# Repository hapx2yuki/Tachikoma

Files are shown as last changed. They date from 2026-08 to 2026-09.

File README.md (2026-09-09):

# タチコマ歩行ロボット化プロジェクト

`TACHIKOMA.3mf` (可動フィギュアの 3D 印刷キット) を、**12 サーボで歩行し、
2 本の可動腕 (キット準拠の固定爪を持つ) を持ち、スマホから操作できる
ロボット**へ改造するプロジェクト。

**2026-09-05 第2次監査結果:** 実サーボの占有、固定部品内部、挿入経路、材料別接触、実制御とSTL変換まで検査し、再現した不具合を修正。
全STL/URDFを再生成したが、頭内収納・頭固定・首/Cabin・脚装飾・足裏支持に未解決事項があり、そのまま組立歩行できる設計とは判定していない。
本文の旧「全検証PASS」は当時の検査範囲の記録であり、組立・実機歩行の合格を示さない。
公開候補の最新記録は[2026-09-09再開監査](docs/audits/20260909-resume/README.md)です（WIP）。
これは実印刷・実組立・通電・歩行の完了を示しません。設計の根拠・残課題は[第2次監査](docs/audits/20260905-round2/README.md)と
[監査Issue #80](https://github.com/hapx2yuki/Tachikoma/issues/80)を参照。

**追加で揃えるもの:** [印刷優先構成の現在地](docs/print-first.md) / [追加購入の全一覧](docs/additional-purchases.md) / [追加印刷・再使用の全一覧](docs/additional-printing.md)。必要総数と手持ちの確認済み数量を区別し、設計未確定の部品を発注・一括印刷する指示にはしていない。[全Issuesの更新内容と着手条件](docs/issues-audit-20260905.md)も参照。

> **Disclaimer / 免責**: 本プロジェクトは『攻殻機動隊』に登場するタチコマを
> モチーフにした**非公式・非営利の個人ファン制作**であり、士郎正宗氏・
> 講談社・Production I.G ほか原作の権利者とは一切関係ありません。
> 商用利用・販売は意図していません。
>
> **License**: コード (`tools/` `hardware/src/` `firmware/`) は
> [MIT](LICENSE)。3D モデルデータ・ドキュメント・メディアは
> [CC BY-NC-SA 4.0](LICENSE-MODELS.md) (非営利・表示・継承)。
> ビルドして遊ぶのは自由ですが、モデルデータの商用利用はできません。

- 意匠シェル: 元モデルを 150% で印刷 (全長 ~38cm)、印刷機は Bambu Lab X2D
- 脚: 3DOF×4 (股ヨー/股ピッチ/膝)。**全軸 20kg 級標準サーボ (DS3218 系,
  デュアルベアリング出力軸)**。骨格は新規設計、シェルを被せて外観維持
- 腕: 3DOF×2 (肩ヨー/肩ピッチ/肘 = MG90S)。手は**キット準拠の固定爪**
  (2026-07-29 可動グリッパから変更: 「爪は可動不要」というユーザー方針に
  基づき、可動グリッパ機構 [palm_base/grip_slider/grip_finger + サブ
  マイクロ×2] を廃止し、元キットの Claw_Grey [爪ハブ] + Finger_Black×3
  [指, 差込] + FingerTip_Grey×3 [指先チップ, 接着] を無加工のまま前腕終端
  の claw_mount へ接着する構成に単純化)。**実機準拠でシャーシ前縁下面から
  吊り下げ**、寸法はキット実測比率 (肘→爪直結の短い腕。3MF フォレンジクス
  実測で前腕を 24→16mm に再短縮)。**意匠は元キットパーツ**: 上腕 = Arm
  ポッドのクラムシェル被せ、肘 = Elbow 球の半殻、爪ハブ/指/指先チップは
  無加工のキット STL そのもの。プリセット TUCK/READY/REACH/WAVE + 各軸
  個別操作 (肩ヨー/肩ピッチ/肘の 3 軸のみ、グリップ軸は無し)
- 制御: ESP32 + PCA9685 ×2 (0x40 脚+頭 / 0x41 腕+目)。WiFi AP (操作UI
  フォールバック) + STA (iPhone インターネット共有へ join) + スマホブラウザ
- 歩容: 回転順クロール (RL→FL→FR→RR) + 重心シフト 前脚 34 / 後脚 40mm + 中立足先を実重心側
  (y=-39mm, Cabin が主因) へ 30mm オフセット → 実重心基準の静的安定 +10.9mm (2026-09-04)
- **目**: **元キットの目パーツ (Head_Eye_White) の形状をそのまま可動化**。
  左右 2 目は白い扁平ドームの黒ドット群 (モールド穴を黒仕上げ) がキャップ軸
  から ~45° 偏心しているため、サブマイクロ ×2 の自軸回転だけで視線が泳ぐ
  **キョロキョロ機構** (掃引径 ~28mm。ランダムサッカード/正面固定/スキャン
  の 3 モード + 歩行方向への視線バイアス)。**中央目は固定カメラ目**
  (下記「カメラ」参照, 2026-07-28 設計変更)。Head_Top の目ソケット
  (φ42.3 座グリ, STL 実測) の底へ φ30 貫通ボアを開け (Head_Top_Eyecut.stl
  生成済み)、シェル内側から嵌める
- ギミック: WS2812 LED (目バックライト/赤ランプ)、DFPlayer サウンド。頭部は
  完全固定 (可動部なし, `docs/assembly.md` §3)。未実装の頭部ヨーに対応する
  CH_HEAD/ch12は、現在のfirmwareでは常時出力停止。
- **音声会話**: 砲身 (Mouth_Cannon) 内蔵のマイク (INMP441) + スピーカー
  (φ20mm, MAX98357A アンプ経由) で、Wi-Fi 越しのブリッジ
  (`tools/voice_bridge.py`) と STT→LLM→TTS (声クローン) の音声会話ができる
  (半二重運用。詳細は `docs/voice.md`)
- **カメラ (2026-07-28 頭部の中央目へ移設)**: **頭部の中央可動目を固定
  カメラ目に置換したもの** (`eye_pod_camera`, 瞳径φ10mm) に独立 WiFi
  カメラモジュール (推奨: Seeed XIAO ESP32S3 Sense) を内蔵。ポッドの
  メインアイ (Cabin_Eye) は元パーツのまま無加工。撤去理由: ポッド前面の
  位置は前方視界の約80%が自機体に遮蔽されることが実測で判明したため
  (`tools/check_camera.py` [4])。瞳をキャップ軸から偏心させ正しい取付
  位相でグルーすることで、ソケット法線の仰角 (~46.6°) を相殺し光軸を
  ほぼ水平前方 (残差 ~8.6°) へ向ける。本体制御 (ESP32-WROOM/PCA9685) とは
  無関係に自前で WiFi 接続し静止画/MJPEG を配信、`voice_bridge.py
  --camera-url` が発話のたびに1枚取得して LLM へ画像として渡す
  (「見て」答えられる。詳細は `docs/voice.md` §5)

## ディレクトリ

| パス | 内容 |
|---|---|
| `model/` | 3MF から抽出した元パーツメッシュ (58 個, 参照用) |
| `hardware/src/` | パラメトリック CAD (Python + manifold3d)。`config.py` が寸法の正 |
| `hardware/stl/` | 生成された印刷用 STL |
| `firmware/` | PlatformIO (ESP32 Arduino)。IK/歩容/Web UI/LED/サウンド/低電圧保護 |
| `docs/` | BOM / filament / 配線 / 印刷 / 組立 / 音声会話、プレビュー画像・動画 |
| `tools/` | 抽出・干渉/ネジ肉厚チェック・歩容シム・ビジュアル生成・音声ブリッジ |

## クイックスタート

```bash
# 1. STL 再生成 (config.py をサーボ実測値に合わせてから)
.venv/bin/python hardware/src/build_all.py
.venv/bin/python tools/make_head_eyecut.py
.venv/bin/python tools/export_urdf.py

# 2. 全検証セット。未使用の空ディレクトリを指定し、失敗も保存する
.venv/bin/python tools/run_design_audit.py --phase verify --output-dir outputs/audit-verify

# 3. ファームウェア書き込み (ESP32 を USB 接続して)
cd firmware && ../.venv/bin/pio run -t upload
```

**2026-07-31 頭部中央寄せの経緯 (解決済み)**: 「頭部中央寄せ」タスクで
`ARM_MOUNT_HUB_Y` を 12→0 (完全中央) にしたところ、頭部シェル実ソケットに
追従する腕マウント位置が前脚側へ12mm後退し、**腕肩マウント×前脚coxa
ブラケットの静的実体干渉** (`check_arm.py`[1]/[1b]/[4], `check_screw_
bosses.py` chassis arm tab) が発生し、「完全中央は物理的に不可能」と
判明した。続く「境界スイープ (実現可能な最中央値確定)」タスクで
`hub_y∈[0,12]` を実メッシュで直接スイープし、全チェッカーが緑になる
最小値 **`hub_y=11.0`** (旧12.0からわずか1mmの中央寄せ) を実測で確定・
採用した。当時のチェック一式はOK/PASSだったが、2026-09-05に実ケースの占有と全固定部品を含めると成立しないことが判明した。過去の数値根拠・
スイープ表は `docs/assembly.md`「頭部中央寄せ」§6-7 参照。

操作: WiFi「Tachikoma」(パスワードは firmware/src/config.h の AP_PASS — 各自設定) に接続 → http://192.168.4.1/

### 音声会話 (任意)

```bash
# オフライン疎通試験 (API キー不要、実機不要)
.venv/bin/python tools/voice_bridge.py --mock --self-test

# 実運用 (要 OPENAI_API_KEY / ANTHROPIC_API_KEY / ELEVENLABS_API_KEY /
# ELEVENLABS_VOICE_ID。iPhone インターネット共有への STA 接続手順は
# docs/voice.md 参照)
.venv/bin/python tools/voice_bridge.py --host tachikoma.local

# カメラ連携あり (頭部中央目内蔵カメラの静止画を発話ごとに LLM へ渡す。任意)
.venv/bin/python tools/voice_bridge.py --host tachikoma.local \
    --camera-url http://<camera-ip>/capture
```

口調・性格は `tools/voice_persona.md` を編集してカスタマイズする。

## 進め方 (重要)

**片脚 1 本を先に印刷してベンチ試験すること** (`docs/assembly.md`)。
サーボ実測 → config.py 更新 → 再生成 → 検証 5 点 → テスト印刷 →
**1.2kg リフト試験**、に合格してから全パーツを印刷する。

## 設計検証の状態 (2026-07-28, 放射配置 v3・実測レイアウト反映後)

- IK/FK 往復: 誤差 0mm
- 歩容スイープ 41,600 姿勢 (速度全域 × 体高 110-130): IK 失敗 0
  (v3: 膝リミット円へのワークスペース射影クランプ込み)
- 静的安定マージン: 最悪 **+10.9mm** (実重心 `CG_XY` y=-39mm 基準, 全指令方向。
  非対称スタンス 前+18°/後-2° + 足先パターン後方 30mm + SWAY 前34/後40 / LEAD 0.11)。
  2026-09-04 以前の「+8.8mm」は重心=原点の誤仮定で、実重心では旋回時 -23.7mm だった (S-01)
- 関節干渉: **サーボ実体込み**で単脚全 8 姿勢 (標準+ミラー) ゼロ /
  **45° ペア (FR-RR/FL-RL)** は firmware 2 段クランプ (単側 17.5°+和 26°) の
  最悪配分 × IK 到達極値姿勢でゼロ / 遠ペアはフルヨー ±40° でゼロ /
  **ポッド (Cabin) vs 後脚** ポッド側ヨー 30° でゼロ (接触開始 34°) / バッテリークレードル
  vs 脚 ゼロ
- タブビス肉厚: 全穴 70% 以上充填 (ミラー版 _m 含む)
- 静的トルク: 股ピッチ最悪 **18.5kgf·cm** (総重量 3.0kg, 実重心, 全指令×全位相の 3/4 点支持
  静力学) vs DS3218 定格 20kgf·cm@6.8V / ~18@6V → **余裕ほぼゼロ** (L-02 ベンチで実測。
  旧記載 8.9 は 1 点評価だった (S-02))
- 脚リンク曲げ強度: tibia 膝ネック SF 2.1 / femur SF 6.4 (`check_leg_link_strength.py`,
  荷重 3.8kgf 動的込み, PETG 55MPa)。2026-09-04 以前の tibia はネック 11mm² で SF 0.1〜0.3 (M-01)
- 折り畳みガード (planar<0 でヨー0): 導入前は折り畳み姿勢のヨーで手先が
  股ゾーンへ -13mm 進入 (数値再現) → 導入後 [4] 全グリッド +4mm。
  目標側+スルー後の実姿勢側の 2 段で評価
- 腕 (check_arm.py 全 8 項目): 肩マウント開口/ボス肉の実メッシュ整合 /
  肩ブラケット・上腕 vs coxa の実メッシュブーリアン干渉ゼロ (腕ヨー±15°×
  脚ヨー±40° でクリアランス 4.1mm — **2026-07-28 腕マウントを Head_Bottom
  実ソケット (正面から放射外向き±40°) 直下へ移設**したため前脚との角度差が
  35° に縮小、旧 v3 の 34.5mm から大幅に縮小したが実メッシュ干渉は依然ゼロ。
  粗近似モデル [4] は最悪 2mm 相当まで保守的に出るが、同じ実メッシュブーリ
  アンで上腕クリアランス ≥5mm を別途確認) /
  肩ピッチ 0.84kg·cm (50g ペイロード込み 38%, 2026-07-29 固定爪化で
  ペイロード/リーチとも縮小し旧値 1.30kg·cm/59% から低下) /
  claw_mount↔爪ハブ接着継手の成立性 (近位面残差 max0.04mm, 指ペグ位置
  claw_mount 外側) / 高さ帯別脚モデルで全姿勢グリッド非進入 / 両腕相互
  接触なし (クランプ後の手先中心 x 最小値 28.5mm — 放射マウントで旧来の
  前向き中立より大幅に余裕) / 地面ガード後の手先最低高さ 41.9mm
  (2026-07-29 固定爪化でリーチ短縮に伴い旧値 12.5mm から拡大) /
  **firmware の腕長定数 (ARM_REACH_MM=47.70, 2026-07-29 固定爪化で
  旧79→ほぼ半減。worst-case reach の実メッシュ裏取り [3b] 追加) と
  腕マウント定数 (ARM_MOUNT_X_MM/ARM_MOUNT_YAW_DEG) を config.h 実読で
  実寸と突合** /
  **殻パーツ 6 点の単一連結体+watertight とポッド↔骨格・前腕掃引
  (肘0-95°) 干渉ゼロ**
- 目 (check_eye.py, 2026-07-28 中央目カメラ化後): 左右2目の眼球/キャリアの
  実メッシュ整合 (ホーンアーム/ハブ逃げ/元キット由来のドット穴 ×3) / 視線
  マーク掃引径 28mm・ドットが座グリ縁に隠れない / モジュール奥行き 51mm <
  ドーム内半径 60mm / 組付けスタック (回転眼球背面 vs ケース上面 1.6mm) /
  **実測ソケット位置での左右サーボ+中央カメラ収容** (指定ロールで左右尾部間
  41.9mm、中央カメラ(実メッシュ)-サーボ間 22.6mm 以上)
- ファームウェア: 通常 + CALIBRATION_MODE の両ビルド成功 (実機未検証)
- 音声ユニット (check_audio.py 全 38 項目): 加工版 (Cannon/Neck/Ball _Bored)
  の外殻が元メッシュと一致 (加工は内部のみ) / スピーカー・マイク実寸ダミー
  収容 / クレードル最小肉厚 0.8mm / 回転キーの誤挿入防止 (180° 回転で干渉) /
  配線ボア連通・極以外の外殻無傷。ブリッジは `voice_bridge.py --mock
  --self-test` でプロトコル往復 (ptt→PCM→tts) が PASS
- **カメラユニット (2026-07-28 頭部中央目へ移設, check_camera.py 全 20+ 項目)**:
  ポッド前面のメインアイは前方視界の約80%が自機体 (シャーシ下面/クレードル)
  に遮蔽されることが `robot_meshes(dress=True)` 全アセンブリのレイキャスト
  で判明したため、中央可動目を固定カメラ目 (`eye_pod_camera`) に置換 —
  eye_pod_camera が加工域以外で元 Head_Eye_White と外殻一致 (最大ズレ
  <0.1mm) / 光軸設計 (θ=38.0° 偏心, 完全水平相殺 46.6° は材の肉厚不足で
  断念) を実ソケット法線・install_rotation から再計算し config 値と一致
  (残差仰角 8.59°, ±10°要求を満たす) / 光学 FOV 68.7° (Seeed 純正 OV2640
  データシート実測, 確認日2026-07-28) が瞳径Φ10・レンズ後退距離6.57mmで
  ケラレ無し (半径マージン0.51mm) / camera_carrier + モジュール実寸ダミー
  (Union Image/Seeed純正データシート実測) が実姿勢でキャビティへ収容・
  壁厚安全代0.22mm以上を実メッシュで確認 / **全アセンブリ視界検証**: FOV
  円錐サンプルの自機体遮蔽率 0% (旧ポッド案の80%遮蔽から解消, 恒久回帰
  チェック) / ネック径28mm<ボア30mm・瞳が座グリ縁より8.1mm上で可視。
  `voice_bridge.py --camera-url` は取得失敗時も画像なしで継続する設計
  (`--mock --self-test` は従来通り画像なしで PASS 維持を確認)
- **UNVERIFIED**: 実印刷はめあい (特に claw_mount↔爪ハブの接着面, 2026-07-29
  固定爪化で可動グリッパ小物から置換)、実重量 (~3.0kg 見込み、固定爪化での
  軽量化分 [推定-50g程度] は未反映の概算)、
  実歩行、サーボ実寸 ([要実測] 値) — 物理製作フェーズで確認。音声ユニットも
  実機 I2S・実物 INMP441/スピーカー寸法 (`config.py` の [要実測] 値)・
  iPhone テザリング実接続は未検証 (幾何検証とモック疎通のみ)
- **フルドレス表示 (kit_assembly) の敵対的監査反映 (2026-07-28)**: 監査で
  「埋め込み2mm」等の自己申告値が実メッシュ (shin_shell()/thigh_cap()) の
  signed_distance 実測と乖離していると判明した Leg_Shin_Guard_Grey_x4 /
  Leg_Thigh_Guard_Blue_x4 / Head_Insert_Black_x4 を、実メッシュに対する
  signed_distance ベースの数値フィット (6自由度差分進化) で再導出
  (tools/data/kit_assembly_front.json の各 "matrix"/"method" 参照。
  Leg_Thigh_Guard は 75.3%embed/最大2.33mm浮きまで改善、Leg_Shin_Guard は
  ガード自体の曲率が shin_shell と完全には一致せず 73.0%embed/最大
  6-7mm局所残差が残る — 現物合わせでの追い込みが必要)。
  **Leg_Shin_Guard 再々フィット (2026-07-28, 監査 major#7 対応)**: 上記の
  73.0%embed 版を独立にハイライト再レンダしたところ、指摘通り視覚的には
  依然扇形に浮いて見えると確認 (`guard_shin_HL_c.png` 相当)。目的関数に
  最大突出量への二乗ペナルティを追加して再フィット (`fit_shin_guard3.py`)
  した結果 embed% は 82.8% (median 1.58mm) まで改善したが、max float は
  6.90mm→6.55mm とわずかしか縮まらず、再レンダでも見た目はほぼ変化しな
  かった — **ペナルティを強めても max float が頭打ちになる**という事実は
  「ガード自体の曲率が shin_shell と一致しない」という診断を数値で裏付ける
  独立エビデンスになった (単なる推測ではなく実際に目的関数を変えて確認済み)。
  新しい配置 (embed%/median は明確に改善、p95/max embed はほぼ同等) を
  採用しつつ、完全な解消には shin_shell() 側かガードメッシュ自体の再設計が
  必要であることを `docs/assembly.md`/JSON に明記した。Cabin 側は
  Cabin_Turrent_Left/Right・Cabin_Front_Insert_Left/Right の L/R 割当を
  source_offset で確定 (ASSUMPTION→CONFIRMED)、Cabin_Front_Insert_Bottom_Wide_Black
  の暫定位置を追加、**Cabin_Front_Blue だけ 3MF の source_object_id が
  他119パート全てと異なり、source_offset を絶対位置の裏取りに使えないこと
  を新規発見** (tools/data/kit_assembly_rear.json meta.methodology_caveats_2026_07_28
  参照 — Head/Cabin 間の絶対配置も同じ理由で source_offset 非適用)。
  カメラ内蔵タスクに合わせ dress 描画の Cabin_Eye も `Cabin_Eye_Bored.stl`
  参照へ切替済み (瞳ボアが `docs/vis_proportions.png` 等のレンダで見える)。
- **タレット向き90°誤り修正 + 後部装飾の向き総再監査 (2026-07-29)**: ユーザー
  指摘「白い砲台がキャビン面に垂直に刺さっている (正しくは面に平行に寝る
  べき)」を実測で確認・修正。原因は2つの複合バグ: (1) Cabin_Turrent_Left/
  Right_Grey 自身の取付フランジ軸は raw STL のローカル +Z から約102°ずれた
  斜め軸 (sharp-edge ring 実測+最大平面facet実測で確定) なのに、rear JSON
  の既定処理は局所+Zを法線に揃えていた。(2) 旧 outward_normal がキャビン側
  リング法線を Front シェルの ghost 回転 (rot(180,'z')@rot(90,'x')) 未適用の
  まま (=ローカル座標のまま) 記録していた。タレット自身の bbox 中心が実
  フランジ中心から8.58mm (スケール後) ズレている点も含め、`tools/kit_assembly.py`
  に front JSON 由来の "matrix" 直接適用パス (rear 対応は今回追加) で解決
  (フランジ中心/法線残差ともに構築上0、干渉チェックで貫入0.001-0.004mm =
  数値誤差レベルに収束)。同じ「法線未回転」バグが Cabin_Eye_White (13.8°
  ズレ) と Cabin_RedLight_Large 前面ペア (~80.8°ズレ、Y/Z 実質入れ替わり)
  にも見つかり同手法で修正。加えて Cabin_RedLight_Large/Small・
  Cabin_Spinnarette_Grey は raw STL の実軸がローカル Y (既定の Z ではない)
  と判明 (section() 断面積スイープで確認、Spinnarette はテーパー付きで
  向きにも意味がある) — `kit_assembly.py` に `LOCAL_AXIS_OVERRIDE` を新設し
  一般化して修正 (旧 `NORMAL_FLIP_PARTS` を包含)。Cabin_Front_Insert_* (矩形
  スロット系) は今回のリング抽出手法では confident に再測できず現状維持・
  UNVERIFIED。詳細は `tools/data/kit_assembly_rear.json`
  meta.methodology_caveats_2026_07_29 参照。check_leg_assembly/check_arm/
  check_camera/check_eye/check_screw_bosses/check_audio/sim_gait は全て
  引き続き OK (今回の変更は tools/kit_assembly.py と
  tools/data/kit_assembly_rear.json のみ、firmware/hardware 側は無変更)。
- **監査指摘の修正反映 (2026-07-28, 足/カメラ/適用トラック横断レビュー)**:
  - **[critical, 修正済]** `leg_foot_bored()` の tibia 差込プラグに追加して
    いた抜け止めリップが、tibia_link() 側の定径ソケットボアと 21.68mm³
    食い込み、PLA/PETG の剛体同士では物理的に挿入不能だった。リップを
    廃止し接着剤保持に単純化 (`hardware/src/make_leg.py`)。回帰検知用に
    `check_leg_assembly.py [8]` で組付け位置での実体ブーリアン交差を
    恒常検査するよう追加 (0.0000cm³ で OK)
  - **[major, 修正済]** `leg_foot_bored()` に `simplify(0.01)` が無く、
    書き出した STL を再ロードすると非 watertight (euler=-1) だった。
    `simplify(0.01)` を追加し、`lib.export()` 自体も書き出し後の実ファイル
    を再ロードして watertight 判定するよう修正 (以後の全パーツで同種の
    見落としを構造的に防止)
  - **[major, 部分対応/残課題あり]** `Leg_AnkleJoint` 非使用により露出する
    甲の取付タブ (3本) のうち、どのトゥ取付にも使われない1本 (-90°側の
    細いポスト) だけを安全に短縮した。残る2本 (+40°/+140°) はトゥの
    実接着面 (最近接 2.7-2.9mm) のため残置 — 完全な解消にはトゥ接着位置の
    再設計が必要で今回のスコープ外 (`hardware/src/make_leg.py` 内コメント、
    `docs/printing.md`「足 (Leg_Foot 化)」参照)
  - **[major, 文書化]** カメラ推奨部品 (Seeed XIAO ESP32S3 Sense) の
    OV2640 センサーは既に廃止され、現行在庫は FOV/EFL 未確認の OV3660 —
    発注前の要確認事項として `docs/BOM.md` #34・`config.py` に追記
    (確認日2026-07-28)
  - **[minor, 回帰検査追加]** Leg_Toe_Black_x12 のトゥ相互重なり/足本体との
    重なりが一回限りの検証で恒常チェックになっていなかった点を
    `check_leg_assembly.py [9]` として追加 (トゥ相互重なり0、トゥ↔足本体
    重なりはトゥ体積の1.23% — 接着代として許容範囲内)
  - **[minor→解消, 2026-07-28 追加調査]** `config.CAM_BOSS_XY/CAM_BOSS_FRONT_Z`
    と rear JSON 実測位置の 56mm 級ズレを再調査した結果、原因は
    「`Cabin_Front_Blue` の shell_ghosts 配置定数の誤り」ではなく、
    **`CAM_BOSS_XY/CAM_BOSS_FRONT_Z` 自体がメインアイの台座ではない別の
    (たまたま Cabin_Eye_White と近い半径の) 円形特徴を掴んでいたこと**と
    判明。rear JSON の Cabin_Eye_White (高信頼) を shell_ghosts 変換で
    局所座標へ逆変換した位置、および `Cabin_Front_Blue.stl` を独立に鋭角
    エッジリング検出した位置 (半径11.9/13.7mmの同心円ペア、rstd<0.001mmの
    綺麗な円) が2-4mm以内で一致したため、これを新しい台座位置として採用
    (`config.py` CAM_BOSS_* 参照, 座標訂正後の残差は3.9mm)。`make_camera.py`
    を再生成し `check_camera.py` 全18項目 OK (watertight・干渉体積0.00mm3を
    再確認)。詳細な導出根拠は `hardware/src/config.py` の CAM_BOSS_XY 直前の
    コメントに numbered evidence として記載
  - **[minor→部分解消, 2026-07-28 追加調査、2026-07-28 再監査で「完全に
    解決」の主張を訂正]** カメラ内蔵用にボア化した `Cabin_Eye_Bored` が
    正面レンダで「青いシェルに埋め込まれた小さな三日月状スリット」にしか
    見えなかった件、根本原因の一つは上記ボア位置ではなく
    **`tools/kit_assembly.py` の向き付けバグ**だった: rear JSON の
    `outward_normal` 整列が既定でパーツの局所 +Z を法線へ向けるが、
    `Cabin_Eye_White`/`Cabin_Eye_Bored` だけは raw STL 自身の Z 規約が逆
    (可視の先端が Z 負側、Cabin_Front 台座への接着縁が Z 正側 —
    `make_camera.py cabin_eye_bored()` のドキュメント通り) のため、既定の
    向きだと広い接着縁が外を向き、可視の先端 (ドーム面) が殻の内側へ引っ込ん
    でいた。`NORMAL_FLIP_PARTS = {"Cabin_Eye_White"}` を追加し、このパーツ
    だけ局所 -Z を法線へ向けるよう修正 — **これ自体は正しい修正**で、目パーツ
    単体 (自身の殻メッシュのみとの遮蔽判定) では白いドーム+瞳の黒い点として
    正しく視認できることを確認済み。
    ただし2026-07-28 の再監査で、**この単体検証が全体組立の遮蔽を見ていな
    かった**ことが判明: `eye_raycast_render.py` (前回セッションの検証根拠)
    は Cabin_Front の殻メッシュと目の2メッシュだけをレイキャスト対象にして
    おり、シャーシプレートや脚付け根ブラケット等フルドレス組立の他パーツを
    含んでいなかった。全121パーツ (`make_visuals.py robot_meshes(dress=True)`
    の実際の出力) に対して同じ判定をやり直したところ (目パーツだけを識別用
    フラグ色で塗り、`docs/vis_proportions.png` と同じ3視点 [側面
    elev=8/azim=0, 前方3/4 elev=16/azim=115, 正面 elev=4/azim=90] で
    900×900px レンダしてフラグ色ピクセルを走査。側面視点は独立に
    占有オクルージョン正しいレイキャスト [trimesh ray-triangle] でも再確認)、
    **いずれの視点でもフラグ色ピクセルは1つも現れず (0.0000%)** —
    メインシャーシプレート (ネジボス配列) と脚付け根ブラケットに完全に
    隠れており、向き付けバグを直しただけでは実際のフルドレス外観として
    「白いドームが見える」状態には**なっていない** (未解決)。よって
    「完全に解決」という前回セッションの結論は誤りで、実態は「目パーツ
    自身の向き付けバグは修正済みだが、他パーツによる遮蔽で外観上は依然
    ほぼ何も見えない」が正しい。`docs/vis_proportions.png`
    (`make_visuals.py stills` で再生成済み) でも同じ遮蔽が確認できる。
    完全な解決にはメインアイをさらに前方へ突き出すか、シャーシプレート/
    脚ブラケットの該当領域を後退・切り欠きする設計変更が必要 — 本セッションの
    スコープ外の残課題として明記する
  - Leg_Shin_Guard の再フィット (最大突出量も目的関数に加えた3回目の
    differential_evolution) は下記「主要な設計判断の記録」および
    `tools/data/kit_assembly_front.json` 参照。2026-07-28 に signed_distance
    で再検算し、記載の 82.8%embed / median 1.585mm / max float 6.552mm が
    現行コードで再現することを確認済み (`shell_mod.shin_shell()` と
    `kit_assembly_front.json` の matrix は変更なし)
  - **[major, 修正済]** 上記 82.8%embed の数値は非ミラー脚 (FL/RR,
    `shin_shell()`) に対してのみ検証されており、実際に `shin_shell_m`
    (Y ミラー) を描画に使うミラー脚 (FR/RL) では同じガード行列をそのまま
    流用していたため、signed_distance で実測すると 26.7%embed / median
    -1.80mm / max float 15.97mm まで悪化することが判明 (`kit_assembly_front.json`
    自身の「not checked this session」という未検証 TODO が的中した形)。
    `tools/make_visuals.py` robot_meshes() で、FR/RL の場合のみガードに
    フィット済み行列を適用した後で Y ミラー (`diag(1,-1,1,1)`) + 面法線の
    再反転 (`mesh.invert()`) を追加適用するよう修正 — ミラーは等長変換
    (距離を保存) であり `shin_shell_m` の構築チェーンとも可換であることを
    数式的に示した上で、実際に signed_distance で再検証し FR/RL が FL/RR と
    寸分違わず同じ 82.8%embed/median 1.585mm/max float 6.552mm になることを
    確認済み（リポジトリ内の検証用スクリプトで再現）。
    4脚とも同一の再現性のある結果になったため、README/docs の数値に脚別の
    注記は不要 (`tools/data/kit_assembly_front.json` の Leg_Thigh_Guard_Blue_x4
    側にあった同種の未検証 TODO も、thigh_cap には `_m` 変形版がそもそも
    存在しない — 脚ごとに位置だけが変わり形状はミラーされない — ことを
    確認して合わせて解消した)

## 主要な設計判断の記録

- MG92B (micro) 12 軸案は重量解析で棄却 (総重量 ~2kg に対しトルク利用率
  ~80% で余裕なし) → 全軸 20kg 級へ
- 両持ちクレビス+アイドラー案は棄却 (STD サーボはケースが反対側空間を
  貫通する) → ホーン片持ち + デュアルベアリングサーボ指定
- ラテラルクロール順は棄却 (対角遷移で重心シフトが相殺) → 回転順
- 腕タワー式マウント (シャーシ上に立てて頭の高さに肩) は**実機写真との
  照合で棄却** — 実際のタチコマは腕が球体前面下部・ノーズ両脇から吊り下がる
  → シャーシ前縁の MICRO ヨーサーボ (脚ヨーと同じ上挿し・軸下向き) から
  肩ブラケットを吊る方式へ全面変更
- **放射配置 v3 (2026-07-28)**: 完成フィギュア (元キット作者ご本人の作例) の下面写真
  実測から、脚は 4 方向均等ではなく **前脚±75°/後脚±120° (正面基準)**、
  真後ろ 180° はポッド接続ネックのステーションと判明 → LEG_MOUNT_DEG =
  {15,165,210,330} へ全面変更。45° ペア (FR-RR/FL-RL) は同一形状 4 脚では
  **中立ですら股ピッチサーボ同士が 3.6cm³ 干渉** (実メッシュ) → **FR/RL を
  ミラー脚 (_m パーツ)** にして解消。ポッドは pod_neck 梁 (隠し構造材) +
  キット TailJoint_Blue コーンの化粧被せで「足と同じ高さの後方」に接続。
  バッテリーはプレート下面クレードルへ (低重心化)。中立スタンスは
  前+18°/後-2° の非対称 (フィギュアのポーズ準拠)。2026-09-04 に実重心 (y=-39mm) を
  反映し足先パターンを 30mm 後方へ・後脚 SWAY 40mm へ (安定 +10.9mm)
- **腕マウントを実機ソケットへ移設 (2026-07-28)**: 公式フィギュア下面写真の
  実測で判明していた「8 ステーション放射ハブ = マウス+腕±40°+前脚±75°+
  後脚±120°+ポッドネック180°」(pitfalls #38) を、実際に Head_Bottom_Blue.stl
  を実測して裏取り。鋭角エッジ連結成分法でリング検出すると、中央 (マウス砲
  ソケット, 前方軸から0.15°) の左右に対称な 2 リングがあり、位置角・ソケット
  法線角ともに前方軸から **±39.9°/+40.1° (平均40.0°)** — 旧マウント (16,74)
  =正面±12° は無関係な干渉回避の名残と判明し、実ソケット直下 (shell_ghosts
  の Head_Bottom 配置経由でロボット座標へ変換, ≈(31.7,49.8)) へ移設。中立
  ヨー (yaw=0) は前向きでなく**放射外向き 40°** (`ARM_MOUNT_YAW_DEG`) —
  firmware の手先位置モデルは `sin(ARM_MOUNT_YAW_DEG+yaw)` に全面書き換え
  (旧式は y を無視し前向き固定を仮定するバグだった)。前脚 (75°) との角度差
  35° が新たな最接近だが実メッシュ干渉ゼロを確認 (下記)。新マウント位置は
  シャーシ中央の ESP32 スロット (旧 (0,40)) と実体衝突したため ESP32 を
  (0,-12.5) へ移設。標準穴の充填・隣接ケース開口 (前脚/腕サーボ) とのクリ
  アランスは `tools/check_screw_bosses.py` の実メッシュ検証で健全と確認
  (前脚ケース開口とのクリアランス最小 ~1mm)
- 腕ヨーは中立向きから常時 ±15° (実メッシュ掃引で確定。脚ヨーは v3 で ±40°
  に緩和)。内側ヨーはさらに手先中心 x が~14mm を割らないよう自動制限 (両腕
  接触回避、放射マウントで大幅に緩和 — 実測 min 28.5mm)。折り畳み姿勢
  (planar<-5) はヨー 0 固定の折り畳みガードに加え、**放射マウント固有の
  新ガード**: ヨー0 に戻すだけでは sin(MOUNT_YAW+yaw) の符号が負に転じて
  手先が反対側 (他方の腕の領域) へ回り込みうる (pitch85°×elbow95°で数値
  再現) ため、ピッチを起こして planar が -5mm を割らないようにする
  (地面ガードと同型の while ループ)。wave/歩行スイングの重畳は**クランプの
  前段**に置く。リミットは目標角と実姿勢 (スルー追従中) の両方で評価
- 手先の床潜り指令は地面ガード (体高連動) でピッチを寸止め
- 目は**ホーン中心ビスを使わない** (密閉眼球で被せた後にビス経路がない)。
  ホーンを先に眼球へ共締め → スプラインへ押し込み。無負荷なので摩擦保持で
  足り、位相残差は目トリム (±200µs≈±18°) で吸収 — スプライン半歯 (≤±12°)
  を必ずカバーできる。進行方向の視線バイアスは vy (+Y 前)
- 目は 3 回の反復で確定: 初版「卵型ポッド+小瞳」→ ユーザーレビューで棄却
  (実物に見えない)。v2「独自造形の真球+青レンズ象嵌」→ ギョロ目に見えると
  再棄却。**v3 = 元キットの目パーツ Head_Eye_White の形状をそのまま流用**
  (白い扁平ドーム+黒ドット 3 つのモールド)。ドット群が軸から ~45° 偏心して
  いるため**傾け機構すら不要** — 自軸回転だけで視線が泳ぐ (掃引径 ~28mm)。
  意匠の要のパーツは独自造形せず、元キットの形状を機構側に取り込むのが正解
- 目ソケットは **STL 実測で前提が覆った**: 開口は仮定 φ30.5 でなく φ42.3 の
  座グリで、しかも底が塞がっている (方位 0°/±90°・仰角 47°、リム 128 頂点円
  で実測)。→ 底へ φ30 貫通ボアを開け (tools/make_head_eyecut.py)、ネック
  φ24 を通してシェル内側から嵌める。[要実測] タグの値を設計前提にする前に
  モデルがあるなら測る
- 3 モジュールのサーボ尾は頭部中心下方へ収束する (法線仰角 47°) — ロール
  無規定だと尾部間 <1mm になり得る。**ケース長辺 = 水平接線方向**の規定 +
  浅いモジュール (キャップ式で奥行き −16mm) で 17.3mm を確保
- 「頭が小さく見える」指摘 → 実測監査で**部分スケールなし**を確認
  (Head_Top_Eyecut = 元 Head_Top ×1.5 で完全一致、全加工パーツが C.SCALE=1.5
  一律)。さらに完成図 (3MF サムネイル) と照合して解剖を確定: **前面の球体 =
  Head 一式が本体の顔** (可動目 3 つ・下にマウス砲・両脇に腕)、**Cabin は
  背中に載る箱型ポッド** (前面にメインアイ Cabin_Eye+赤ランプ)。動画で頭が
  小さく見えたのは骨格のみの表示だったため。キット配色フルドレス表示
  (`tools/kit_assembly.py`, 3MF forensics 準拠の意匠パーツ配置) の
  `docs/vis_proportions.png` (make_visuals.py stills) で比率を確認できる。
  **[訂正: 2026-07-29] 当時 Arm_Right_Claw_Grey (爪台座トライポッド) を
  「薄殻の開放骨組みでサーボ入りパームを収める内腔が無く、グリップ機構
  [grip_finger/palm_base] と干渉するため不使用」と結論したが、これは
  Arm_Right 版 (爪ハブと無関係の別形状) の話であり、可動グリッパそのものを
  廃止した現行のキット準拠固定爪化 (ユーザー方針「爪は可動不要」) では
  Arm_Left_Claw_Grey (実際の爪ハブ, 両腕鏡映使用) を claw_mount へ接着して
  使う。詳細は hardware/src/make_arm.py claw_mount() docstring / 上記
  「腕」節参照**
- **頭部圧縮の実測根拠 (2026-07 追加)**: Head_Bottom_Blue/Head_Top_Blue の
  継ぎ目ギャップ (shell_ghosts の旧値 60mm=57-(-3)) を 3MF `Metadata/
  model_settings.config` の `source_offset` から独立に裏取りした。Head_Bottom
  自身の上端リム (raw z=8.461, r=41.46) と Head_Top 自身の下端リム (raw
  z=-32.009, r=41.78 — 全メッシュ中の最大半径 = 赤道面の開口) は球殻を
  上下に割った本当の継ぎ目そのもの (ほぼ同径, 間に Head_Plate_Grey という
  1.82mm厚のガスケット円板が挟まることも source_offset で裏付け済み)。
  両リムが面一になる Head_Top オフセットを計算すると **+57.7 — 旧値 +57
  との差はわずか 0.7mm**。前セッションが残した「実測は42.3mmで60mmは
  17.7mm過大」という finding は、独立検算しても数値が再現せず**誤りと判明**
  したため訂正 (tools/data/kit_assembly_front.json Head_Top_Eyecut の
  "finding" に全計算過程を記録)。同じ調査で Mouth_Cannon/Mouth_Neck を
  Head_Bottom 相対で再導出することも試みたが、両者とも 3MF 上で
  Head_Bottom_Blue と直接接触 (bbox-gap 0.00mm) する関係が無いため、
  同じ置換手法を延伸すると物理的にありえない位置 (マウス砲が顔球体の前方
  8.6mm に浮く等) を返す — **source_offset 置換は 0.00mm 接触ペアでのみ
  信頼できる**という教訓を得た (詳細は同 JSON の Mouth_Cannon_Grey
  finding)
- 腕 v3 の敵対的レビューで 2 系統の実害を検出・修正: (1) **firmware の
  ARM_REACH_MM が 73 のまま実リーチ 79 と drift** し地面ガード余裕が実質
  2mm まで目減り (定数を 79 に修正 + check_arm が config.h を実読して突合
  する方式へ — 定数の複写は drift を検出できない)。(2) **輸入メッシュ×
  ブーリアンの殻パーツが非連結化** (ポッドのリブ孤立片 108mm³ / 肘殻の
  欠き貫通 2 分割)。生成側で最大連結成分のみ残す+欠きを y≥-6 に限定し、
  check_arm [7] で単一連結体を恒久検査
- **カメラ内蔵 (2026-07-28 追加)**: メインアイ (Cabin_Eye_White) は STL実測
  で中心軸上に空洞の無い完全なソリッドと判明 (「LEDが透ける」は元々スライサー
  の壁2/インフィル設定だけで実現され、STL自体に導光構造は無い)。定径の
  単純貫通穴だとレンズ後退距離=全厚14.8mmが必要になり、光学FOV 68.7°
  (Seeed純正OV2640データシート実測) をケラさない径がΦ21相当まで肥大して
  「瞳として自然に見える最小径」の要求に反する → **段付きボア** (先端寄りの
  狭い瞳チャンネルΦ12+奥の広いリリーフ空洞Φ26) でレンズを先端7.25mmまで
  近づけ、Φ12のまま68.7°全域でケラレ無しを達成。さらに実装中、
  camera_bracket (モジュール実寸 20.5x12.5x5.54mm 保持) を素朴な円盤
  フランジで Cabin_Front の台座前面へ当てる設計が**実測で1400mm3超の食い込み**
  を起こすことを検出 — 台座前面は単純な平面ではなく**ドーム状** (半径17mm
  以内で最大2.2mm相当の凹凸、意匠トリムの影響で回転対称でもない) だった。
  Cabin_Front_Bored (座グリ加工版, 鉄則1の_Bored系に準拠) を追加して解消
  (check_camera.py [3] が加工前後の干渉体積比較を恒久記録)。カメラモジュール
  自体は本体の PCA9685/I2C バスと無関係な**独立WiFiユニット**として設計
  (iPhoneテザリングへ自前で接続し静止画/MJPEGをHTTP配信、voice_bridge.py
  --camera-url が発話ごとに1枚取得しAnthropic APIへ画像として渡す。取得
  失敗時も音声パイプラインは画像なしで継続)
  **[2026-07-28 追記: この配置は下記「頭部中央目カメラ化」でポッドの
  メインアイから頭部の中央目へ移設された。上記の Cabin_Eye_Bored/
  Cabin_Front_Bored/camera_bracket は撤去済み — 以下は当時の設計記録として
  残す。]**
- **頭部中央目カメラ化 (2026-07-28, カメラ内蔵の再配置)**: 上記のポッド前面
  メインアイ内蔵カメラ案を、**robot_meshes(dress=True) の全アセンブリ
  レイキャストで前方 FOV の 80% が自機体 (シャーシ下面/クレードル) に
  遮蔽される**ことを検出したため撤去 (「見える/視界」系検証は部分メッシュ
  ではなく全アセンブリを対象にすべき、という教訓が確立: 部分メッシュは
  自己遮蔽しか見えない)。ユーザー決定により、**頭部の中央可動目を固定
  カメラ目に置換**する設計へ変更 (左右2目はキョロキョロのまま維持)。
  ポッドのメインアイは元 Cabin_Eye_White へ復元 (無加工)。
  中央目ソケットの法線は仰角 ~46.6° (ほぼ真上向き) のため、瞳をそのまま
  キャップ軸上に開けると光軸は空を向く — 既存のキョロキョロ機構と同じ
  「ドット群がキャップ軸から偏心する」原理を流用し、瞳をキャップ軸から
  角度 θ 偏心させ、正しい取付位相でグルーすることでソケット仰角 α を
  相殺する幾何 (残差仰角 = α − θ, 軸・法線が同一鉛直面内にあることの
  帰結) を導出。完全相殺 (θ=α=46.6°) は Head_Eye_White カップ (φ37.7 の
  小さな扁平ドーム) の材が薄く、偏心が大きいほど瞳位置がドーム縁に近づいて
  カメラモジュール (20.5×12.5×5.54mm) を収める肉厚安全代が取れないため、
  実メッシュへの多方向レイキャスト探索 (0.5°刻み, モジュール footprint の
  実姿勢フィット) で **θ=38.0° が安全代込みで成立する上限**と判明 —
  残差仰角 ~8.6° (要求 ±10° 以内を満たす)。新パーツ eye_pod_camera (瞳
  ボア+モジュールキャビティ加工版, 外殻は元 Head_Eye_White のまま) /
  camera_carrier (子基板保持+シェル接着) を追加。tools/check_camera.py を
  全面書き換えし、[4] として全アセンブリ FOV 遮蔽率を恒久チェック項目に
  追加 (旧 Cabin_Eye 案の 80% 遮蔽が今回 0% に解消したことを回帰的に保証)。
  BOM #2b (サブマイクロ) は目駆動サーボが 3→2 個になり 5→4 個に削減。
  firmware `eyes.h` の Eyes::update() は左右 2ch のみ駆動し、中央 ch (25)
  は未使用として予約したまま残す (配線/PCA9685 割当を変えないため)。
- **shin_shell ループ意匠 (2026-07-31, ユーザー指摘の再検証 → 方針転換)**:
  Leg_Shin_Blue_x4 に造形されたリング/ハンドル状の突起が機体外側を向いて
  しまっている、という指摘に対し、当初 `shin_rotz` を 90→270° (+180°)
  へ回転させれば内側化できると考えて実装したが、レビューで再検証した結果
  **誤りと判明**: 実スタンディング姿勢・実カメラ視点で確認すると 90°/270°
  どちらでもループは "内向き" ではなく "横向き" (機体中心から見て
  50-65°、依然外側から視認できる) にしかならない。0°/90°/180°/270° を
  総当たりした結果、真に内側 (176°程度) を向くのは shin_rotz≈0° のみだが、
  この角度では脚断面の厚い側が隣接脚を向くため 45°ペア (crouch+最大内寄せ
  ヨー同時) で shin_shell 同士が 7-9cm³ 交差する新規の重大干渉が生じ、
  局所リリーフでは対応できない規模と判明 (シェル片側の壁をほぼ全長にわたり
  削ることになり "飛び出した部分を削る" という許可の範囲を超える)。
  **Z 回転 1 自由度だけでは「ループを隠す」と「可動域を確保する」を両立
  できないという教訓** — 最終的にはループ/ハンドル意匠そのものを
  raw メッシュ座標系上の固定位置で直接切除する方式 (`shell_mod.py`
  `LOOP_RELIEF_*`, 回転より前段で適用するため shin_rotz の値に非依存) を
  採用し、回転は元の 270° (隣接脚干渉が最小の角度帯) を維持した。
  この過程で、check_leg_assembly.py が shin_shell を自脚/隣接脚検査に
  一度も含めていなかったこと (今回 `tools/check_shin_arm_leg.py` を新設し
  解消) に起因する 2 件の未発見の既存不具合も判明: (1) 深い股ピッチ+膝
  屈曲での shin_shell×femur_link 干渉 (ループ・回転値に非依存、0.22-0.26cm³
  → KNEE_RELIEF で解消)、(2) 45°ペア crouch+最大内寄せヨーでの
  tibia_link×tibia_link 干渉 (0.07cm³、shin_shell 非依存の骨格側不具合、
  未解消・対応範囲外として報告継続)。さらに check_arm.py も脚を粗近似
  モデルでしか扱っていなかったため、shin_shell と READY 姿勢の腕との
  広範囲干渉 (10.7cm³ 相当、局所リリーフ不可能な規模) も新規発見 — こちらも
  未解消で、firmware 側の脚×腕 姿勢連成クランプ等、別レイヤでの対応を
  推奨事項として残す。詳細な数値・検証根拠は `docs/assembly.md` §3、
  `tools/data/kit_assembly_front.json` (Leg_Shin_Guard_Grey_x4 の
  matrix_note_2026_07_31/b)、`tools/check_shin_arm_leg.py` を参照。
- **shin_shell 装飾面の放射外向き確定 (2026-07-31, 実物写真提示による再修正)**:
  ユーザーが実物 (塗装済み完成品) の写真を提示し「脚の側面パーツは全て
  放射軸から見て外側を向いている」ことが確定。raw `Leg_Shin_Blue_x4.stl`
  上で 3 点ドットモールド (中心 raw≈(13.4,0,37.7), 平均法線 raw≈(0.85,0,0.52))
  と主パネルライン (raw X∈[12.3,17.1] のシェルほぼ全長にわたる sharp-edge
  帯) を幾何学的に特定 — いずれも上記ループ (raw X<-5 帯) の正反対の面。
  4 脚の実スタンディング IK 姿勢での完全なキネマティクス (T_knee 合成)
  スイープにより、`shin_rotz=0.0°` で 4 脚全て cos_sim=1.000 (完全放射外向き)
  になることを数値確定 (旧 270° は隣接脚干渉回避のための妥協値で、
  ドット面はほぼ真横を向いていた)。270°→0° への変更で新たに生じた
  45°ペア隣接脚 crouch 干渉 (無対策で最大 8.49cm³) は、放射内向き
  (外から見えない) 側だけを Z バンド別に削る `ADJ_RELIEF_BANDS` で解消
  (M3 ボルト座面という締結上のハード制約により 0.84cm³ の既知残留あり、
  `shell_mod.py` `BOLT_BOSS_KEEPOUT_X` 参照)。腕 (READY) との干渉は
  270° 時の 10.65cm³ から 7.91cm³ へ改善。`Leg_Shin_Guard_Grey_x4` の
  取付行列も新しい壁形状に合わせて再フィット (80.1%embed/median1.71mm/
  maxfloat3.53mm)。詳細は `docs/assembly.md` §3、`shell_mod.py`
  `OFFSETS`/`ADJ_RELIEF_BANDS` コメント、`tools/check_shin_arm_leg.py` を参照。
- **shin_shell のリリーフカット再評価 (2026-07-31, 「削る理由が消えたカット」
  の撤去)**: タスク#30 で確立した「firmware 到達可能集合内 (`pk_reachable()`,
  `gait.h` の `D_KNEE_MIN`/`D_KNEE_MAX` ワークスペース射影の不動点条件) で
  干渉するか」という判定基準を、KNEE_RELIEF / TIP_RELIEF /
  ADJ_RELIEF_BANDS+BOLT_BOSS_KEEPOUT_X の3カットに統一適用して再評価した。
  結果、3カットとも到達可能集合内では干渉ゼロ (旧干渉はいずれも
  crouch(pitch45°,knee30°) 級の到達不能姿勢でのみ発生していた) と判明した
  ため撤去し、キット形状 (機能上必須の UPPER_CAVITY/LOWER_CHANNEL/BOLT_ZS
  以外は無加工) へ復元した。LOOP_RELIEF (ループ意匠切除) は復元を検討した
  が、UPPER_CAVITY (機能上必須の空洞) がループの付け根をちょうど切断して
  しまい常に非連結の浮遊片 (1.12cm³) になってしまうため、印刷可能な形での
  復元は不可能と判明し維持した。撤去後、`Leg_Shin_Guard_Grey_x4` の取付
  行列は無変更のまま embed 80.1%→87.4% へ自動改善 (壁復元の副次効果)。
  shin_shell 重量は +17g/セット (~147g→~164g)。`tools/check_shin_arm_leg.py`
  [B] の shin-shin 判定も tibia-tibia と同じ到達可能集合基準に統一し、旧
  KNOWN_BOLT_BOSS_CEILING 特例を削除。全検証スクリプト (check_shin_arm_leg.py
  /check_urdf.py 380項目/check_leg_assembly.py/check_screw_bosses.py) が
  green で再確認済み。詳細は `docs/assembly.md` §3「2026-07-31 リリーフ
  カット再評価」、`shell_mod.py` 該当コメント、`docs/urdf.md` (Isaac Sim
  上での自己接触に関する注記を追加) を参照。

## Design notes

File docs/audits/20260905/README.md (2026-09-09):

# タチコマ独立監査 — 2026-09-05

**現状のまま実機が安定して歩けるとは判定できない。通常立位でもトゥがTPU足裏より先に接地する、機構上の重要な問題が残っている。**
一方、操作画面・安全停止・起動・音声・シミュレーション・印刷データ生成・Issue運用の再現可能な不具合は、ローカルで修正と回帰検証を行った。

作業ブランチ: `codex/audit-20260905`。開始時は `42aa7fd`、未コミット変更なし。
監査開始時の307追跡ファイルをリポジトリ外へ退避済み（場所は [baseline.json](baseline.json)）。
キットの外観、CAD寸法、STL、既存3MF、旧動画・旧測定JSONは保持した。
GitHubにはIssueと依存関係を反映。コードはローカル変更であり、push・実機書込み・印刷・追加購入は実施していない。

## 最優先の未解決事項

### 足裏支持の前提が成立しない — RV-06 / #87

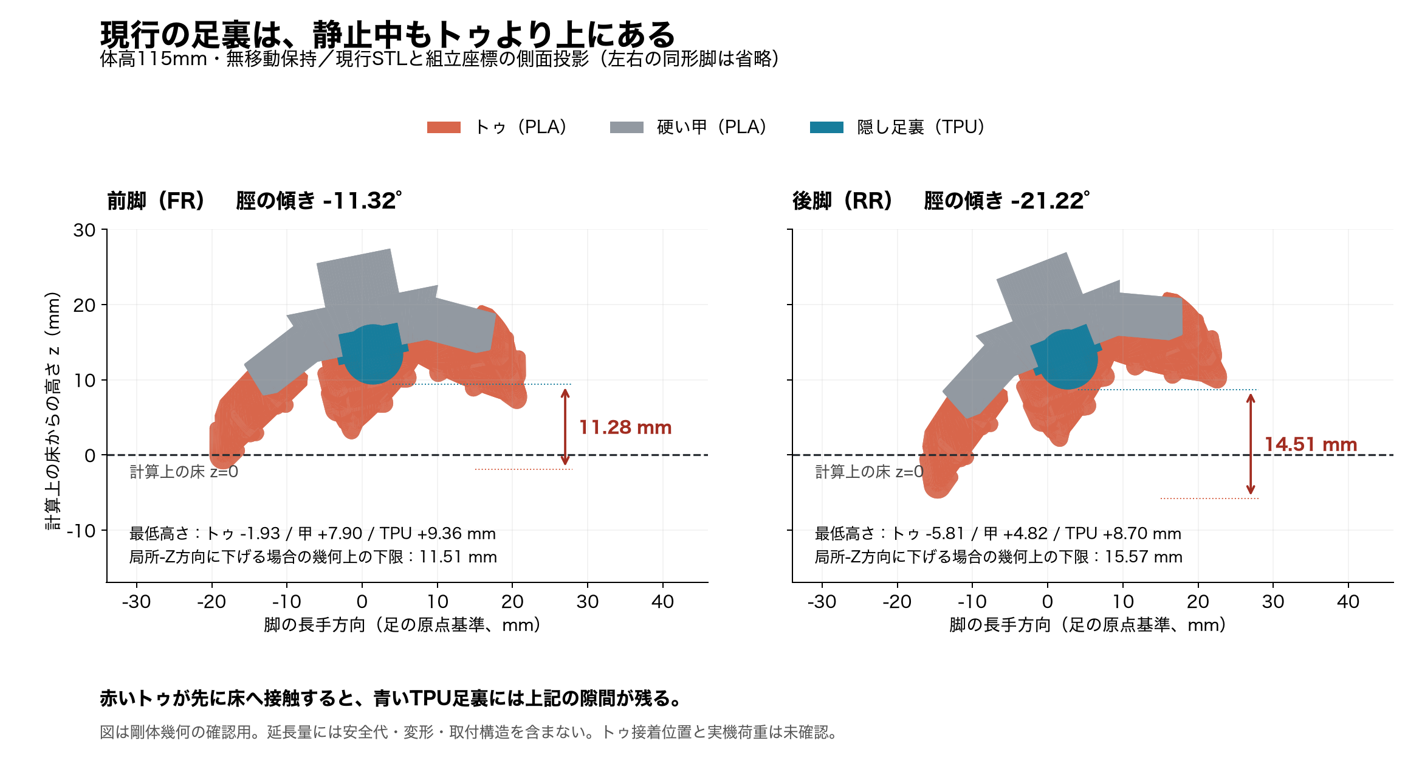
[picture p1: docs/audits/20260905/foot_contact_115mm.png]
現行足先の位置関係


体高115mmの停止保持で、前脚のトゥはTPUより11.28mm、後脚は14.51mm低い。
これは床への実際の沈み込み量ではなく、同じ脚のどの部品が先に触れるかを示す差である。
体高110〜130mm・小歩幅〜最大指令を走査した324,020姿勢のうち、接地相243,020姿勢すべてでトゥが先行した。
トゥを外しても硬い足本体がTPUより先に触れる姿勢がある。

従来の接地検査は「硬い足本体とTPUを合わせた最下点」を見ており、TPUへの荷重を確認していなかった。
MuJoCoも足全体を単一凸包・同じ摩擦で扱う。したがって、数値シムで歩けても、細いトゥや接着部の耐荷重・実際の滑りは証明できない。

単純な足裏延長では、既定保持の後脚だけで局所軸方向に最低15.57mm、今回の歩行範囲では最大26.39mmが必要となる。
安全代・取付強度・座屈は含まない。外観と歩容への影響が大きいため、この長さの部品を無検証で追加する修正はしていない。
**次は現物のトゥ取付姿勢を図と照合し、元形状を保存した内部支持・着脱支持の具体案を決める。**
足の接着位置は元記録でも確度に限界があるため、現物照合が必要。

根拠: [機構監査](mechanical.md)、[診断JSON](toe_contact.json)、[Issue #87](https://github.com/hapx2yuki/Tachikoma/issues/87)。
新規診断 `check_toe_contact.py` はこの未解決問題に対して終了コード1を返す。

### 印刷物の強度と動力の余裕 — RV-07 / #88、既存 #37 / #75 / #77

- 既存の強度検査は中実断面・文献強度による計算。4壁/40%充填の印刷物を実測した結果ではない。
  壁と低密度コアを分けた感度計算では、pod_neckの安全率が2.71〜2.79となり、既存要求3を下回った。
  これは実破断の確定ではなく、実荷重・たわみ試験を省けない根拠。
- `claw_mount_L.3mf` には腕7部品が壁2/15%で保存されている。そこから印刷した品を4壁/40%の強度前提で扱わない。
- 静的股ピッチ最悪18.50kgf·cmは既存閾値20以内だが、購入したサーボの6V連続保持能力・発熱は未測定。
  電源の連続容量、電圧降下、実重量・重心も、実機の計測で確定する。

根拠: [強度感度JSON](strength_sensitivity.json)、[Issue #88](https://github.com/hapx2yuki/Tachikoma/issues/88)。
感度計算も要求未達を終了コード1で報告する。既印刷品の廃棄・一括再印刷は指示していない。

## 修正した欠陥

| 対象 | 変更前の問題 | 今回の修正 |
|---|---|---|
| 操作画面 | 変数初期化前の参照でJavaScriptが停止し、操作を初期化できない | 実行順を修正。通信断・画面非表示時に移動/PTTを零化 |
| 腕と脚 | 脚のスルー前目標で腕退避を早く解除する | 目標とスルー後の出力角の危険側を使う。実測角ではない点を明記 |
| 起動と停止 | 順次通電がフラグ操作だけ。校正モードは低電圧・脱力でも出力継続 | 100msごとに実PWMを1軸ずつ出力。校正でも低電圧ラッチと脱力を反映 |
| 指令の共有 | 通信処理と制御処理で状態が競合、部分指令が脱力を解除し得る | ロックした指令状態を制御周期に反映。不正値・非有限数を拒否 |
| 音声 | INMP441に必要なI2Sスロット幅、リング状態、通信処理、TTS送信間隔に欠陥 | PCM16bitを維持して32bitスロット化。通信/リング/送信間隔の回帰を追加 |
| 配線説明 | PCA9685 VCCをESP32の3.3Vへつなぐ指定が無い | PCA2枚のVCC、論理プルアップとサーボV+の分離を明記 |
| 幾何・歩容検査 | NGでもexit0、ブーリアン失敗をNaNにして見逃す | 非0終了と計算失敗の明示。既存閾値を緩めず、失敗を注入した試験を追加 |
| 物理シム | 横移動を前進と表示。停止SWAY・50Hz・出力スルーを再現せず、転倒でもexit0 | 実C++との時系列比較、方向別移動量、明示的合否、トルク速度近似と飽和計測 |
| 3MF生成 | foot_padの再生成時にPLA割当へ戻る。手動編集済み3MFを一括上書き | TPU設定保持。別出力先を既定にし、既存ファイルの上書きを明示指定に限定 |
| Issue同期 | 再実行で進捗をTodo/Readyへ戻す。文書の生成節が重複 | 既存Status保持、対象キー限定、依存の明示的整理、重複拒否、再実行の冪等性確認 |

詳細: [制御・音声](firmware.md)、[機構・印刷・配線](mechanical.md)、[シミュレーション](simulation.md)。

## 検証の結果と限界

| 確認 | 結果 | 根拠 |
|---|---|---|
| 全STL→頭部加工→URDF再生成 | 成功。既存hardware/modelの追跡ファイルとSHA-256全一致 | [生成ログ](logs/build-all.log)、[頭部](logs/make-head-eyecut.log)、[URDF](logs/export-urdf.log) |
| 既存の全12チェッカー（脚リンク強度を含む） | 修正後すべて終了コード0 | [最終一覧](logs/final-results.json) |
| 幾何/歩容の失敗検出回帰 | 4件成功。計算失敗・NaN・トルク不足・干渉を拒否 | [ログ](logs/test-audit-gates.log) |
| Issue同期の回帰 | 7件成功。進捗保持、重複、依存整理、排他モードを確認 | [ログ](logs/test-issue-sync.log) |
| 現行の印刷用3MF | 26ファイル101objectの形状一致。数量/弱い印刷条件には要確認あり | [結果](print_artifacts.json) |
| 実C++歩容との比較 | 1,077フレーム、最大差0.000895度。7回帰成功 | [ログ](simulation/regression.log) |
| MuJoCo | 公称・摩擦/重量/トルク変更・後退・横移動等9条件で条件付き合格 | [条件別集計](simulation/scenario_summary.json) |
| MuJoCoの破綻検出 | 摩擦0では数値不安定を検出して不合格・非0終了 | [ログ](simulation/zero_friction.log) |
| 足裏単独支持 | **不合格、未修正** | [図](foot_contact_115mm.png)、[診断](toe_contact.json) |
| 印刷物の強度 | **感度計算で要求未達あり、実測未確認** | [診断](strength_sensitivity.json) |
| 実機 | **UNVERIFIED**。通電・書込み・印刷・荷重試験・歩行をこの監査では実施していない | 既存の実機Issueで確認 |

通常/校正のファームウェアビルドとホスト回帰のログは [制御監査](firmware.md) を参照。
実機の関節符号、PWM範囲、校正、起動・脱力後の経路、I2S波形は別の確認事項。
特に初期角0度から立位への途中姿勢は定常IKの検査範囲に収まるとは限らず、支持台での実機確認が必要。

公称シムの前進は **145.59mm / 比較時間6.4秒**、旋回18.60度、最大roll3.32度、脚の最悪飽和時間率0.262%。
初期状態を立位に配置し、推定質量2.78985kg・剛体・自己衝突なし・全足一様摩擦という条件での値。
摩擦0.25では横ずれ62mmがあり、直進精度も未保証。
[修正版の13秒動画](simulation/forward_nominal.mp4) は実機動画ではない。

## Issueと実際の進め方

既存77件を活用し、今回9件を追加して計86件。既存の物理試験を証拠なしでCloseしていない。
コード修正のIssueも、ローカル検証・コード反映・実機試験の状態を区別して記録する。

| 並行して進める作業 | 最後に合流する条件 |
|---|---|
| [制御 #81](https://github.com/hapx2yuki/Tachikoma/issues/81)、[印刷データ #82](https://github.com/hapx2yuki/Tachikoma/issues/82)、[物理シム #78](https://github.com/hapx2yuki/Tachikoma/issues/78)、[Issue同期 #84](https://github.com/hapx2yuki/Tachikoma/issues/84) | [検査判定 #83](https://github.com/hapx2yuki/Tachikoma/issues/83) と合わせ [統合監査 #85](https://github.com/hapx2yuki/Tachikoma/issues/85) |
| [サーボ実測 #13](https://github.com/hapx2yuki/Tachikoma/issues/13)、[印刷済み棚卸し #12](https://github.com/hapx2yuki/Tachikoma/issues/12)、[足支持 #87](https://github.com/hapx2yuki/Tachikoma/issues/87)、[電源確認 #28](https://github.com/hapx2yuki/Tachikoma/issues/28) | 実測値→config確定→片脚試験 |

```mermaid
flowchart LR
  measure[サーボ・ホーン実測] --> config[寸法確定と既印刷品判定]
  config --> one[PR-04 標準tibia 1本]
  one --> gate[L-02 片脚荷重試験]
  gate --> rest[PR-11 残り3本]
  rest --> legs[L-03/04/05 3脚を並行組立]
  legs --> walk[L-10 頭無し歩行]
  support[RV-06 足裏支持の改修] --> dressed[I-02 フルドレス歩行]
  strength[RV-07 実印刷強度] --> dressed
  walk --> dressed
```

- 電源対策EL-09とトルク対策L-11は、試験の不合格時にも着手できるよう、合格済みIssue待ちを解除した。
- プリンタは1台の作業として直列。本体を同時に触る作業も重ねない。CAD/制御/配線準備の担当ファイルは分ける。
- 既印刷品は版と設定を照合して再利用する。購入済みサーボの交換や昇圧は、型番・実測・電源分離を確認してから判断する。
- トゥの切削や見える形状の変更は、プロジェクトの `AGENTS.md` に従いオーナー判断。今回の診断だけで外観を変更していない。

[監査親Issue #80](https://github.com/hapx2yuki/Tachikoma/issues/80) / [既存Project](https://github.com/users/hapx2yuki/projects/2) / [全体計画](../../build_plan.md)。
依存はGitHubのblocked by関係として登録し、本文だけの説明にしていない。
全86件の親子関係・依存130件を読み戻して計画との一致を確認し、既存の空欄でないStatusは保持した。
根拠: [GitHub照合結果](logs/github-verification.json)。
[GitHub公式の依存関係説明](https://docs.github.com/en/issues/tracking-your-work-with-issues/using-issues/creating-issue-dependencies)に沿っている（確認2026-09-05）。

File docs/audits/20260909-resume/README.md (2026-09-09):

# 2026-09-09 再開監査・公開準備（WIP）

確認日: **2026-09-09（JST）**。対象は、現行 `print-first` 候補、履歴3MFの保護経路、通常物理の限界、頭候補の薄肉分解、公開準備です。公開候補は [PR #111](https://github.com/hapx2yuki/Tachikoma/pull/111) の証拠 [commit `14c3728`](https://github.com/hapx2yuki/Tachikoma/commit/14c372880507462f7eb181a1b75a0ad7b217ccb5) と追補 [commit `a8156fb`](https://github.com/hapx2yuki/Tachikoma/commit/a8156fbfc7539f35f0fbaad25808c44f98247540) の到達履歴として記録・push済みです。外部反映の読み戻しは [github-publication-result.json](github-publication-result.json)（確認時刻: **2026-09-08T19:12:30Z / 2026-09-09 04:12:30 JST**）に保存し、Issue #3〜#109の107件追記、既存コメント16件保持、Project #2の96→107（#99〜#109の11件追加）、依存156→174（18件追加）、親87件保持・循環0を確認しました。現物の印刷、組立、通電、歩行も確認していません。候補生成・検証の入力SHAと成果物はcommit 14c3728と追補commit a8156fbの記録に対応しています。

現時点の判定は **WIP / REVIEW_REQUIRED / 量産・実機未確定** です。今回の頭部確認では、既存の `pf_head_top_clearanced` を監査用に参照しただけで、新しい逃げ形状は作っていません。旧 `pod_neck` 用の重複候補も追加していません。

## 最新の生成結果

2026-09-08T18:28:51Z〜18:32:24Z（`run_id=d93022334ee143b68ee0d06646e8f40e`）の `tools/generate_print_first.py` と `--validate-only` は、いずれも終了コード0でした。生成結果は **86パーツ・23リンク、visual STL 56枚、collision STL 24枚、URDF参照メッシュ80枚**です。Cabin保管後のruntime台帳は29源部品、合計587.3919603718443 g、追加保管568.7360089849115 g（既保管18.655951386932827 gを二重計上せず）です。生成前後の対象ソース236件はSHA差分0、履歴3MF26件は全件保持・SHA一致でした。これは形状・台帳の生成確認であり、実印刷、実組立、通電、歩行、材料強度の合格ではありません。

生成済み候補URDFのruntime bindingは、Cabin保管後の29源部品・追加保管568.7360089849115 gを含めて確定しました。形状変更の根拠へ自動昇格させず、候補URDF・manifest・参照STLのSHAを公開候補へ記録済みです。最新の数値境界と公開向けリンクは [公開根拠要約](public-evidence-summary.md) に集約しています。

同じ候補を部品別に分けた診断は144件で、51 PASS、87 FAIL、6 TIMEOUTでした。FAILの主因はVHACDの表面被覆・検証変換であり、87件を機体欠陥87件とは読みません。現行衝突メッシュの `linked-hulls` 粗い凸包近似は、stand/T0が `INVALID_INITIAL_CONTACT_MODEL`（4.4秒積分、最大初期自己貫入28.1084 mm、roll 24.9095°、pitch 11.5022°）、別の26秒歩行・自己衝突なし診断が `FAIL` でした。これは近似モデルの切り分け結果であり、機構欠陥や歩行合格の実証ではありません。部品別診断のPASS/FAIL/TIMEOUTは、この候補で保存した診断値として扱い、厳密な全構成物理の合格へ広げません。

## 3MFの復元と保護

`Downloads/TACHIKOMA.3mf` は、旧再現記録の実行時に不在でした。過去のJSONや抽出済みメッシュを、元ファイルの再確認や復元済みの証拠とは扱いません。開始時台帳は、リポジトリ内の元モデル58個と印刷プロジェクト27個を記録し、変更前の保護台帳は124ファイルの不変を記録しています。STL差分は12ファイル（形状10、配置のみ2）で、変更STLは閉形状でした。

今回の保護確認では、`hardware/stl` の履歴3MF 26件について、quarantine経路が現位置を保持すること、欠落時に移動前に拒否することを実際の入口で確認しました。履歴3MF保持・欠落拒否2件と生成器契約49件がPASSです。これは `restore_from_backup` / quarantine の保護契約が通ったという意味で、欠在するDownloads原本の復元、実印刷、実機適合を意味しません。元の変更前バックアップはリポジトリ外のため、公開ファイルにはパスを載せません。

ローカル保存根拠（公開束外）: [3MF保護記録](../../../outputs/audits/20260909-resume/artifact-preservation-20260908T171154Z-3mf/README.md)、[検証JSON](../../../outputs/audits/20260909-resume/artifact-preservation-20260908T171154Z-3mf/verification.json)。公開版は [公開根拠要約](public-evidence-summary.md) に集約しています。

## 通常物理PASSの限界

標準 `hardware/urdf/tachikoma.urdf` を `PRINT_FIRST_ACTIVE=False`、`linked-hulls`、通常の13秒条件で実行した記録は、`simulation_acceptance=PASS`、終了コード0でした。有限状態、転倒なし、IK fallbackなし、脚以外の床接触なし、物理警告なしを確認しています。`physical_readiness=UNVERIFIED` です。

このPASSは、標準URDFの指定条件に対する数値診断です。自己衝突は無効、材料別接触は分離せず、print-firstの採用STL・サーボ外形・親子自己衝突・4脚の支持・実購入個体を評価していません。したがって、機体完成・実機歩行・print-first物理成立へ読み替えません。ローカル保存根拠（公開束外）は [通常物理README](../../../outputs/audits/20260909-resume/physics-20260908T163200Z/README.md) と [metrics.json](../../../outputs/audits/20260909-resume/physics-20260908T163200Z/metrics.json) です。公開版の境界は [公開根拠要約](public-evidence-summary.md) にまとめています。

## 電装の最新回復確認

2026-09-08の再確認では、`.venv/bin/pio run -e esp32dev -e esp32dev_print_first -e esp32dev_print_first_cal` が3環境すべて `SUCCESS`、続く `.venv/bin/python -m unittest ...` が57件すべて `OK` でした。`post-verification.json` で、実機書込みなし、入力変更なし、実機未接続・未通電を確認しています。これはホスト回帰とビルドの根拠であり、実機起動・電源能力・歩行・print-first物理完走を示しません。ローカル保存根拠（公開束外）は [回帰の再確認](../../../outputs/audits/20260909-resume/firmware-regression-20260908T171626Z/post-verification.json)、[3環境ビルド](../../../outputs/audits/20260909-resume/firmware-regression-20260908T171626Z/build.log)、[57件回帰](../../../outputs/audits/20260909-resume/firmware-regression-20260908T171626Z/regression.log) です。

## print-firstのbatteryからCabinへの停止

最初のprint-first候補実行では、`base_link/battery_cradle` のVHACD被覆が 21,103/23,026、`0.9164857118040476`、許容値0.011 mmで失敗し、`mj_step`前に停止しました。2026-09-08T17:18Zのbattery特則は1832凸セル、23,026/23,026、被覆率1.0、5帯すべての双方向Boolean対称差0.0 mm²、体積差`-4.9749360187e-09 mm³`でPASSしました。この局所特則はbatteryの形状境界だけを確認し、形状外距離や全体物理を確認していません。

最新のCabin保管後 formal stand/T0（2026-09-08T17:59Z）は事前検査296件がPASSし、入力ソース304件の前後差分もありませんでした。battery経路の後、`base_link/Mouth_Cannon_Grey` の被覆が `16007/19618 = 0.8159343460087675`、許容値0.011 mmで失敗し、`mj_step`前に停止しました。したがって静止姿勢・歩行・実機の物理結果はありません。`FINAL_FROZEN`は入力SHA固定だけを示し、物理合格や採用決定ではありません。17:18ZのCabin停止記録は旧履歴として保持し、現在の採用構成の正式結果には使いません。Cabinは殻・装飾・peg・turretを保管し、`pf_cabin_rail_l/r` の一体電装支柱・棚・battery・chassisを維持する方針です。根拠の要約は [公開根拠要約](public-evidence-summary.md)、詳細なformal記録はローカル監査台帳に保存しています。

## 頭候補の薄肉分解と実壁

旧入口 `.venv/bin/python tools/check_head_pod_clearance.py` は `Head_Top_Eyecut` と `pod_neck` の `89.23001 mm3` 交差を再現してFAILしました。`pf_head_top_clearanced` を同じ旧座標へ戻しても `89.229924705 mm3` で、旧 `pod_neck` 用の逃げがあるとは言えません。現行 `A.context(generated=True)` は `pod_neck` と旧頭殻を収集から外し、`pf_head_top_clearanced` と `pf_chassis` の実メッシュ交差は `0.0 mm3` でした。頭殻・シャーシ・候補は単一連結・watertight、目穴は3/3開口です。

固定乱数24,000面のうち、判定領域10,879点に対する1.25 mm内側プローブは候補 `10176/10879 = 93.538%` でした。失敗703点は次のように分かれます。

| 区分 | 点数 | 扱い |
|---|---:|---|
| 開口・切断端（原本の0.25 mm判定でも外側） | 59 | 薄肉欠陥へ数えない |
| 原本側の浅部・端部 | 61 | 直接断面がないため欠陥とは断定しない |
| 現行print-firstの占有逃げ | 583 | 目・腕・脚・カメラの設計逃げ |
| 未分類 | 0 | — |

開口・逃げを除き、q=1.25 mmから内向きへ法線整合レイを通した実壁は、候補6310本で最小 **1.923876 mm**、5%点1.935294 mm、中央値2.511614 mmでした。最小点の外側座標は `(11.616166, 68.282130, 23.736800) mm`、内側ヒットは `(10.625942, 67.102182, 24.889397) mm` です。支持座は `pf_chassis` の丸角8×12 mm断面で、最小実断面は `(x,y)=(56,35) mm`、`z=13.5 mm` の **50.5659 mm²** でした。座隙0.25 mmは `config.PRINT_FIRST.head_seat_gap` による支持座嵌合値で、旧 `head/pod_neck` の0.5 mm目標を緩めた値ではありません。

この結果は寸法確認用試作候補の根拠です。実サーボ・カメラ適合、PLA層間強度・たわみ、荷重・引抜き、上下殻接合、実印刷面は未確認で、量産可とは判定しません。詳細な数値はローカル保存根拠（公開束外）の [頭部実メッシュ再検査](../../../outputs/audits/20260909-resume/head-20260908T164318Z-pfcurrent/README.md)、[薄肉分解](../../../outputs/audits/20260909-resume/head-20260908T164318Z-pfcurrent/thin-wall-breakdown.md)、[座標表](../../../outputs/audits/20260909-resume/head-20260908T164318Z-pfcurrent/support-sections.csv) に保存し、公開版の要点は [公開根拠要約](public-evidence-summary.md) に転載しています。

## 個数と追加購入の境界

2026-09-06確認の台帳を再照合しました。現行の設計必要数は、body16＋legs20＋TPU靴4＋PLAスペーサー16で **56個**です。初回のAは **31個**（body16＋固有脚10＋TPU靴1＋スペーサー4）、A合格後のBは **25個**、Cは既存脛殻4個の局所加工・再使用が不成立のときだけ選ぶ **条件付き4個**です。CはA+Bへ加算しません。LD-220適合治具3種は各1個の非本番治具で、56個へ加えません。

追加購入台帳の `immediate_purchase_required=0`、対象IDなしは、現在の着手方針として追加購入を確定していないことを示します。`physical_stock_verified=false`、手持ちPLA/TPUの残量・良品数未確認、`current_shortage=null` は、不足ゼロや現物充足を確定しません。`currently_printable_quantity=0` はfreeze2・現物適合・材料・実C++物理試験のゲート未通過を示します。旧全体キット台帳139個、治具、予備、候補形状を本番56個へ混ぜません。

根拠は [print-firstマニフェスト](../../print-first-manifest.json)、[追加印刷台帳](../../additional-printing.json)、[追加購入台帳](../../additional-purchases.json)、[print-first現行説明](../../print-first.md) です。

## full trace / full dynamics

現行候補のbody構成では、[最新body実メッシュ記録](../../../outputs/audits/20260909-resume/native-trace-final-component-20260908T183435Z/final-body-mesh.json)がnative trace 20軸・12区間・全1141行を読み、`pose_rows_read=1141`、`pose_rows_checked=1141`、`fixed_geometry=true`、`dynamic_geometry=true`、交差・エラーなしで `status=DYNAMIC_PASS` となりました。これはbody構成の1ケースについて全1141姿勢を同じ実メッシュへ束縛した結果で、全構成の材料別VHACD・購入サーボ外形・電圧群適合・実機を確認したものではありません。`physical_readiness=UNVERIFIED` です。

一方、`linked-hulls` 粗い凸包近似はstand/T0が `INVALID_INITIAL_CONTACT_MODEL`（初期自己貫入最大28.1084 mm、roll 24.9095°、pitch 11.5022°）、別の26秒歩行・自己衝突なし診断が `FAIL` でした。粗い凸包近似の有限積分結果を厳密VHACD契約や歩行合格へ読み替えません。最終freeze2はWIP公開の前提ではなく、同一SHA台帳による全物理ゲートを後続で実施します。

## 旧来検査の集計

現行候補とは別に、`legacy-verify-20260908T184106Z/verify-results.json` の旧来検査23件は **PASS 14件 / FAIL 8件 / UNVERIFIED 1件**でした。FAILは旧static、arm、leg、head-pod、URDF、print-artifacts、toe、strengthの各検査で、powerはUNVERIFIEDです。この旧来集計は、body全1141姿勢のprint-first `DYNAMIC_PASS`とは別の回帰検査結果であり、実機適合・印刷強度・電源能力を確定しません。

CoACDの一部品調査は [公開要約JSON](mouth-cannon-coacd-public-summary.json) にコピーしています。`DIAGNOSTIC_ONLY` かつ `formal_gate_changed=false` であり、全体の衝突近似へ採用していません。

## 3組のソース候補と再現閉包

公開候補として精選した3組（履歴3MF保護、battery VHACD、native trace入口）は、各ソースと回帰試験だけを並べた6件の対です。現行 `tools/print_first_source_closure.py` が定める38件のソースと15件の追加凍結入力に対する、3組の直接列挙との差分は **50件**です。allowlist生成時点で未追跡と記録した18件のうち、commit 14c3728のHEADでは17件が追跡済みで、残る1件はcanonical `motion-quality`入力として意図的に公開外です。この差分は6件の直接列挙との差分を示す台帳値であり、合成treeから消えた依存数ではありません。不足パスと追跡状態、各組の直接依存は [publication-allowlist.json](publication-allowlist.json) の `source_closure_requirements` / `missing_from_three_pairs` に列挙しました。

今回の候補リストでは、既存の公開allowlist候補のソース群に加え、6件をASTでたどったローカルimport閉包 **31件**、生成器が直列に呼ぶ9段階、電池特則試験が読む `hardware/stl/battery_cradle.stl` を個別選択しました。生成器の静的入力である `tools/data/kit_assembly_front.json` / `kit_assembly_rear.json`、`model/`、全`hardware/stl`は個別の公開選択から外していますが、いずれもHEAD追跡物として仮合成treeで利用可能であり、今回の依存欠落ではありません。既存metadataにある絶対home表記は既公開履歴由来として今回の新規停止理由にせず、私的な調達記録だけは引き続き候補から除外しています。出力・衝突cacheは公開束へ含めないため、`outputs/print-first-20260905/final-simulation/cases/motion-quality-cases.json`だけがcanonical 53件の意図的な合成tree欠落です。

一時 `GIT_INDEX_FILE`でHEADと選択中の候補を合成して確認しました（treeハッシュは候補JSONの`virtual_tree_check.tree_hash`に記録）。選択候補ではgenerator契約49件を **49/49 PASS**、battery回帰4件とnative回帰3件をPASSとして確認済みです。`outputs/`全体やcacheを公開するのではなく、generatorが直接要求する13件を手渡し対象として選定済みです。canonical 53件のうち、motion-qualityの生成入力1件は意図的に公開外です。ソース閉包の差分50件とcanonical出力1件はこの状態を明示したまま、選択候補の再現検査を確認済みです。

## Issue 107件のWIP計画

外部反映の読み戻しは [github-publication-result.json](github-publication-result.json)（`status=PASS`、確認時刻 `2026-09-08T19:12:30Z`）に記録しています。Issue **#3〜#109の107件**へWIPコメントをappend-onlyで追記し、wip marker 107件を読み戻しました。既存コメント16件は保持され、反映後コメント総数は123件です。Issueの本文・タイトル・状態・ラベルは変更していません。

Project #2は既存96項目を保持したまま#99〜#109の11項目を追加し、107項目になりました。依存は既存156本を保持し、18本を追加して174本、親関係87本を維持し、循環は0件でした。ローカル計画との差分を反映済みで、Issue本文への既存内容の置換や実機完成・実印刷完了・物理完走の記載はありません。最終freeze2はWIP公開の前提にしません。実反映の根拠と読み戻し値は [github-publication-result.json](github-publication-result.json) を正とします。

## 公開対象の明示リスト

[publication-allowlist.json](publication-allowlist.json) と [公開根拠要約](public-evidence-summary.md) に、今回のREADME、公開根拠要約、CoACDの公開要約JSON、WIPコメント案、既存公開文書、依存閉包のソース/試験、生成済み現行候補を明示しました。候補は選択パスを個別列挙し、`outputs/`全体・cache・私的な発注情報・絶対homeパス・リポジトリ外バックアップ・元`model/`全体・元`hardware/stl`全体・動画・zip・全未追跡の一括取り込みは対象外です。URDF参照STL80件、body/legs/feetの印刷候補37件とassembly記録3件、generator契約の足部共有1件とXIAO候補12件、LD220治具3件＋記録1件を個別に選定済みです。電池試験用の `hardware/stl/battery_cradle.stl` も必要な原本として個別選定済みです。公開対象はWIP候補であり、量産認定や実機完了を意味しません。今回の既存doc修正は、状態と根拠の整合を取るために記録しています。

内容走査では、allowlistに実際に選んだテキストとSTLについて、絶対homeパス、秘密らしい値、発注番号・郵便番号・メールアドレスを検出しません。公開根拠要約の相対リンクは、選択文書またはHEAD追跡の公開ファイルを指します。raw監査出力は作業ツリーに保管しますが、公開束へ再帰的に含めません。

## 追加した回帰試験

2026-09-09 04:02 JSTに、追加公開する回帰試験2本を`.venv/bin/python`で実行し、`test_print_first_cabin_storage.py`は3件・3.804秒、`test_print_first_gate_hardening.py`は5件・0.065秒で、いずれも`OK`でした。`test_print_first_cabin_storage.py`は、直接CLIのruntime台帳、generated=FalseのCabin源mesh保持、generated=TrueのCabin保管と`pf_cabin_rail_l/r`・棚・`battery_cradle`・`pf_chassis`の維持、質量の二重計上防止を3件で確認します。`test_print_first_gate_hardening.py`は、完全trace必須化、旧freeze状態の拒否、安全な出力先、入力SHA変更の拒否、診断モードの明示を5件で確認します。両方を追加公開する回帰試験として扱います。

## 確認したソースのSHA-256

表は証拠commit 14c3728と追補commit a8156fb / PR #111の到達履歴に含まれる公開ソースSHAです。各実行の入力SHAは個別記録を正とし、途中の診断を最新ソースの検証へ読み替えません。

| 対象 | 確認時点のSHA-256 | 状態 |
|---|---|---|
| `tools/generate_print_first.py` | `1404d9f4849bc806aea89348c7b498f5b6b4c2ba993334072a18ff31eadfd037` | commit 14c3728で生成・validate-onlyを確認 |
| `tools/tests/test_generate_print_first_contracts.py` | `42591c2f305c06efc0879da34d7e4f00155c0d2dc9a0734d64c7a60ec4d9822e` | 保持2件＋契約49件の証跡あり |
| `tools/sim_collision.py` | `a6a0e300b6aa42fdb9df4f9c2bec1e8d211fd28e4014ed7bf47ecd29b0d061e1` | commit 14c3728の現行入力SHA。生成・検証へ反映済み |
| `tools/make_head_eyecut.py` | `071bfba70b6f287d5b45be4d8753e00b62b6422a6ac8b3985b63cdf6b3db41d8` | 現行頭候補生成器、今回ソース編集なし |
| `hardware/src/make_print_first_body.py` | `87e283b6eb7efbce3ca6b82c644ef6649ff95f6eeee72661fac116f71c467408` | commit 14c3728の生成入力として確認済み |
| `tools/print_first_assembly.py` | `4f69d67b646393e0a25e39f611686d3429d54190a238a30d062ef77493ee33fd` | commit 14c3728で追跡・仮合成tree検査済み |
| `tools/print_first_source_closure.py` | `ec525cdc0bfb7a6af9a10f1f64d6589a5d2abe733cf5ec93b6542466d1ae33b3` | 38件のソース＋15件の追加凍結入力を列挙する現行閉包。commit 14c3728で追跡済み、仮合成tree検査済み |
| `tools/tests/test_battery_cradle_feature.py` | `4012b3829b714323e951f07802887f21390fb0b90faf2c5c0b9bb08625a700ea` | commit 14c3728でbattery回帰証跡を確認済み |
| `tools/tests/test_print_first_cabin_storage.py` | `51c000ba3483a3d073be38766cfe4772793b8968a1f05d927071a7d4855be951` | 2026-09-09 04:02 JSTに3件OK。追加公開する回帰試験 |
| `tools/tests/test_print_first_gate_hardening.py` | `0a72aca072777a03b4c5434938709a428a9867449d767f33b3c4c78a2ed5c637` | 2026-09-09 04:02 JSTに5件OK。追加公開する回帰試験 |

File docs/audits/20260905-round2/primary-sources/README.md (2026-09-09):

# メーカー資料の出典と再取得

確認日: 2026-09-05。メーカー原本PDF、ページ画像、STEP入りZIPとSTEPから変換した原形状STLは内部参照用としてローカルに保持する。これらの再配布条件は未確認のため、GitHubには原本を複製せず、出典・SHA-256・測定結果を保存する。利用可否についての法的判断を示すものではない。

| 資料 | 公開元・取得先 | 保存する根拠 |
|---|---|---|
| DS3218仕様 | [DSSERVO資料ページ](https://www.dsservo.com/down.asp?id=22) | 原本/描画のハッシュ、シミュレーションの仮定と数値 |
| OV3660モジュール仕様 | [Seeed仕様書](https://files.seeedstudio.com/wiki/SeeedStudio-XIAO-ESP32S3/new-res/OV3660_Camera_Module_Specification.pdf) | 原本/描画のハッシュ、カメラ候補の寸法・視野検査 |
| XIAO ESP32-S3 Sense 3Dモデル | [Seeed公式案内](https://wiki.seeedstudio.com/xiao_esp32s3_getting_started/)の3D Model、[ZIP](https://files.seeedstudio.com/wiki/SeeedStudio-XIAO-ESP32S3/res/seeed-studio-xiao-esp32s3-sense-3d_model.zip) | 組立変換付き測定JSONと原本ハッシュ |

全体のファイル照合は [source-register.json](source-register.json)。権利者は上表の公開元として記録し、外部の原本/原形状の再配布許諾は `UNVERIFIED` とする。ここに含める寸法測定JSONと `camera_removed_*_envelope.stl` 2個は、本監査で求めた予約領域の数値と単純な直方体であり、メーカーの詳細形状を複製したSTLではない。

XIAO測定を再現する場合は、公式ZIPをこのディレクトリの `xiao-esp32s3-sense-3d_model.zip` として保存し、台帳のハッシュと一致するか確認する。メーカー側で更新されていた場合、過去と同じ入力とは扱わない。

```sh
.venv/bin/pip install --target /tmp/tachikoma-step-runtime 'cadquery-ocp==7.9.3.1.1' 'vtk==9.7.0'
PYTHONPATH=/tmp/tachikoma-step-runtime .venv/bin/python tools/measure_xiao_step.py
```

このSTEPは2023年の旧カメラ世代の参考資料。購入済みの基板・OV3660・ケーブルを実測した値ではない。収納候補の判定には現在の実部品との照合が必要。

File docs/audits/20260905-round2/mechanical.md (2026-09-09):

# 第2次 機構・印刷・組立監査（2026-09-05）

**現行一式をそのまま組み立てて歩かせられる設計とは確認できない。** 腕と音声の確定した内部干渉は修正した。一方で、頭内の実サーボ占有、脚カバーとシャーシ、頭固定、足の接地、配線後の支持強度には未解決の問題が残る。既存検査の PASS と実機成立を同一視しない。

## 対象と検査方法

- `hardware/src` の12 Pythonファイルを全読解。形状生成・取付原点・サーボ向き・ホーン/ねじ・負形状・組立順を確認した。
- `model` の58 STL、`hardware/stl` の41 STL、同ディレクトリの26 3MF、ルートの1 3MFを機械読込した。全頂点/面、有限値、面参照、閉形状、連結数、体積、外包、ZIP CRC、全 `.model` XMLを検査した。表示用の一部だけを対象にしていない。
- `kit_assembly.py`、全配置JSON、`extract_meshes.py`、`make_head_eyecut.py`、印刷生成、脚/ねじ/腕/目/音声/カメラ/首の検査を全読解。新しい診断には元STLの実体ブーリアン、元C++到達姿勢、面断面、レイ、差分体積を使った。
- パス・SHA-256・読み方・結果・根拠は [coverage-mechanical.json](coverage-mechanical.json)。生成後のSTL/3MFの鮮度は最終再集計時点を使う。
- MuJoCo、全体の質量・慣性、URDF、購入ケースを含む全衝突は [simulation](simulation/) の担当検査を参照する。電子回路・電流・購入型番の一次資料は全体報告、Cabin収納は [cabin.md](cabin.md) に分離した。

元の `~/Downloads/TACHIKOMA.3mf` は今回の環境に見つからない。配置JSONの過去の組立座標抽出記録を、元3MFを再読した確認済み情報として扱っていない。ルートの `TACHIKOMA_Phase0_PETG.3mf` は元キット組立プロジェクトの代用にならない。

## 実装・再現済みの修正

| 対象 | 原因と修正 | 確認 |
|---|---|---|
| 腕の肩–上腕 | 0度だけでなく全角度で肩フレームが上腕と交差。実可動域を掃引し、サーボ箱の支持を残して肩の内部逃げを追加 | 下記1283姿勢 |
| 腕の上腕–前腕・肘殻–前腕 | 肘40度でそれぞれ396.10/148.48mm³の実体交差。前腕を逆向きに掃引した内部空間を除去 | 長さ16mm、手首位置、ホーン支持板を維持 |
| マイク挿入 | 着座状態だけが通り、0.5mm戻した位置で21.98mm³、1mmで76.92mm³。通路間の0.72mmの壁が挿入を塞いでいた | 0〜24mmを0.25mm刻み、97姿勢0交差 |
| 口のBall–Neck | 旧形状は1862.66mm³、Neckの約50.73%がBallへ入る | 実球面座を内部に追加、121挿入姿勢0交差 |
| つま先12個の変換 | 行列の倍率だけ100%。印刷仕様150%・JSONの説明と不一致 | 生の根元 `(0,8.375,0)` を保って倍率1.5へ訂正、根元誤差最大1.99e-15mm |
| ブーリアン失敗 | `except: return 0`、None/NaN、負の体積を無干渉としていた箇所 | 共通関数が例外を伝播。ゼロ交差/失敗/不正値を分ける3試験 PASS |
| カメラ遮蔽 | 最初の交点が25mm以内なら丸ごと無視 | 全交点を調べ、0.1mmより先の近距離遮蔽も検査 |
| Head–首 | 基部を自動的に「頭内だから除外」としていた | 実体全体を対象に変更。残る89.23mm³をFAILとして保持 |
| 印刷生成 | TPUのスロットをPETG側に指定し、同名3MFを上書きする危険 | 実テンプレートのTPUスロット6、別出力先、明示上書きのみ許可。3試験 PASS |

腕は肩ピッチ −45〜85度、肘0〜95度を0.25度刻みで再検査した。修正前の最大実交差は肩54.58mm³、上腕–前腕598.56mm³、肘殻–前腕約275.38mm³。ケース追加前の1283姿勢だけでは、固定された上腕–肘殻370.60mm³、肘ケース–殻402.79mm³を見落としていた。ケース底y−19.5mmへカバーの切欠底y−6mmを合わせ、0.3mmの余裕を加え、カバー原球中心を肘軸からy−13.8mmへ移した。元の球面自体は変更していない。

この移設後に前腕へ残った干渉を、肘軸回りで不変の球包絡を用いて逃がした。前腕の除去は148.79mm³、旧前腕の5.04%で、局所x9〜12.838/y−13〜−9mmに限定される。長さ16mm、手首終端面、ホーン支持面の損失はいずれも0。最終sourceは4可動ペア計1664姿勢と固定4項目で全交差0、4部品とも1閉体。18実出力姿勢×左右×全リンクとのカバー比較も0だった。接着固定と実サーボ個体の寸法は別途確認する。[elbow-cover-candidates/arm-joints-source.json](elbow-cover-candidates/arm-joints-source.json)、[source-current.json](elbow-cover-candidates/source-current.json)、[forearm-clearance-material.json](elbow-cover-candidates/forearm-clearance-material.json)

根拠: [arm-joints-before.json](arm-joints-before.json)、[arm-joints-source.json](arm-joints-source.json)、[arm-joints-STL.json](arm-joints-STL.json)、[audio-assembly-before.json](audio-assembly-before.json)、[audio-assembly-STL.json](audio-assembly-STL.json)、[toe-scale-correction.json](toe-scale-correction.json)。既存STLの再生成と標準検査は全体担当が直列に実施した。

前腕は除去後も1連結体で、検査した5断面の最小面積は97.79mm²。ただしこれを印刷後の耐荷重証明としない。ホーン実物の材質、層間強度、穴周り疲労、接着、転倒衝撃は別途確認が必要である。

### 口の挿入とシャーシの受け座

固定部品を全組合せで調べると、口のBall–シャーシ1149.47mm³、Neck–シャーシ115.51mm³、Cap–シャーシ0.219mm³、Cap–Neck112.88mm³が残っていた。これは座標の違いではなく、実体そのものの交差だった。Ball/Neck/Capを配置した負形状に片側0.3mmを加え、シャーシ内側へ必要な逃げを設けた。Cap–Neckには片側0.2mmと引き抜き方向の連続包絡を加えた内部座を作った。

シャーシの正面90度のねじ耳は、逃げだけだと穴周囲が薄くなる。そこだけφ10mm・高さ3mmのカラーを追加し、穴φ3.2mmの外に半径方向3.4mm、上下方向5mmの連続した環状支持を残した。この穴のねじ有効長は旧図から3mm増える。ほかの脚/腕/PCA/電池/首/頭の支持領域は除去0、追加カラーと既存部品の交差0。頭を実際に固定する支柱が未設計であることは別の未解決事項である。

最終sourceはシャーシ1閉体、体積54609.82mm³。口3部品との材料交差0、下側から30mmの挿入を0.25mm刻みで調べた各121姿勢も0。Neckは1492.96mm³の1閉体で、BallとCapの挿入各121姿勢、マイクの97位置が0。これらは隠れた受け座の修正であり、口の原型表面を変更していない。[mouth-chassis-source.json](mouth-chassis-source.json)、[audio-assembly-cap-seat-source.json](audio-assembly-cap-seat-source.json)

### 固定爪と脚Guardに残る組立干渉

手の旧検査は、交差50mm³未満とレイ残差1mm未満を「現物合わせ許容」として合格させていた。根拠がないため廃止した。前腕・mount・爪・指3・指先3の9部品全36組を個別検査すると10組で交差する。mount–爪4.628mm³、爪–指0.058〜0.076mm³、爪–指先15.878〜15.881mm³、指–指先17.071mm³。中心面のレイ残差は最大0.0397mmだが、面の一致だけでは全形状の組立を保証しない。元の圧入量・公差・挿入経路が未確認なので、`check_hand_assembly.py` と `check_arm.py` はNGを維持する。原型の可視指形状を勝手に削っていない。[hand-assembly/final.json](hand-assembly/final.json)

脚Guardは旧配置最適化が支持殻へ約1mm埋める目的で作られ、実受け座が未生成だった。ThighGuardの1211.94mm³（約81%）、ShinGuardの1146.76mm³（約78%）が殻へ食い込む。Guard側だけを切る候補は各210〜211mm³、3体/2体へ分裂したため不採用。支持殻側の受け座も6候補を検査した。局所4案は1閉体でも26方向への初動がすべて干渉。開放大腿案は外面724.7mm²を失い、開放脛案は542.5mm²を失って283mm³が分離するため、いずれも不採用。骨格との交差も残る。意匠部品同士の交差を接着代として通過させない。[guard-seat-candidates.md](guard-seat-candidates.md)

## 足裏：実際の150%つま先で再評価

倍率修正前の表示モデルのつま先は長さ16.75mm、体積730.45mm³だった。印刷された150%形状は長さ25.125mm、体積約2465.28mm³。第1次監査の接地差は前者に対する数値であり、実物150%の結論として再使用してはいけない。

150%修正後、既定体高115mmの無移動保持で、最も低いつま先は基準地面から **−13.335mm**、TPU足裏は **+8.699mm**、差は **22.034mm**。硬い足本体もTPUより3.875mm低い。4脚全てでつま先が先に接地する。体高110〜130mm、停止保持・その場SWAY・4段階の歩幅を調べても問題は消えない。[toe-contact-after-scale.json](toe-contact-after-scale.json)

有限な改修候補を、体高5種・命令13種・96位相・4脚の24,960姿勢から得たピッチ+膝の範囲 −42.073〜8.978度で比較した。図は [foot-support-candidates/comparison.png](foot-support-candidates/comparison.png)、全数値は [comparison.json](foot-support-candidates/comparison.json)。

| 候補 | 最低接地差/必要な変更 | 判定 |
|---|---|---|
| 足ソケットの小さな回転 | ±15度内の最良でも硬部がTPUより最大24.04mm低い | 小変更だけでは全範囲を満たさない |
| 全角度の回転探索 | 360度全域1441候補でも最良が−9.91mm | 向きだけで解決しない |
| 球面支持R15 | 全域2.073mm先行接地。ただし旧足裏より底面を36.59mm延長 | 外観・たわみ・体高への影響が大きく不採用 |
| つま先下面のTPU靴1.5mm | 全域1.642mm以上先行接地。足本体との交差約4.7e-7mm³ | 見た目変更を伴う候補として保存。現行STLへ未採用 |

TPU靴は各つま先の現物150%形状に沿わせ、内側の足本体との接合部だけに隠れた座を設けた。元の根元は各29.0〜29.6mm³が足本体へ交差していたため、単なる「接着代」として無視しない。試作形状の連結片1個を除いた場合も、除去量34.91mm³を記録している。

荷重は最悪の1本へ3.8kg×0.6×g=22.37Nを与えた単純曲げで、根元の最大応力2.64MPa。接着接触面47.0〜49.5mm²に対する平均力は0.45〜0.48MPa。**これは接着の許容値ではない。** 剥離、2g以上の衝撃、薄い足側の局所破壊、摩擦係数、TPUクリープを未確認として残す。別材接触モデルでの横滑り比較はsimulation担当の候補試験へ渡した。

## 頭内：ケースを含めると成立していない

下向き軸の脚ヨーサーボは、取付タブから本体が上へ伸びる。現行寸法ならケースはchassis z7〜35.2mmに達する。`make_head_eyecut.py` は反対側の `ABOVE_TAB` を使い、高さ18mmの仮箱で頭内を削っていた。腕側も実ケースはz6〜25.5mmに対して旧仮箱12mmだった。

独立した全ケース検査では、脚ヨー–目本体/保持板、脚ヨー–HeadTop、肩ピッチ–前脚ピッチに数百〜数千mm³の交差がある。同じ固定リンク上の部品同士はMuJoCoの自己接触として出ないため、別の組立検査が必須である。4ケースだけで得られた旧収納候補は目のサーボ/保持板を含まず、採用できない。詳細は [simulation/all-pairs-native-20servos-before-final.json](simulation/all-pairs-native-20servos-before-final.json) と収納探索記録を参照する。

購入済みの機種は資料間で不一致がある。DS3218、Hiwonder LD-20MG、LD-220MGの3系統を同一外形として扱わない。メーカーのDS3218図のタブ下27.7mmとconfig28.2mmにも0.5mm差がある。ケースの主箱だけでも不成立なので、この差によって問題全体が解消することはないが、再製作の前に実購入機種を確定する必要がある。

### カバーとシャーシ固定

保持姿勢のchassis–thigh_capは前脚約116mm³、後脚約411mm³。外面2万点試験でも前脚532/519点、後脚1278/1290点がシャーシ材料内にあり、前脚は全て上向きの可視外面である。内部を中空化するだけでは直らない。

前脚の交差半径は69.35〜84.83mm、後脚は72.03〜87.10mm。取付耳だけを削除/内寄せしても前脚は本体円板r72と交差する。coxa–capの保持時約10.7〜13.6mm³も別に残る。無断でカバー上面を欠く加工は実施していない。

頭固定の7穴はr78にあるが、7本とも垂直軸線がHeadTopを通らない。頭位置の1mm不一致をconfigの11mmへ統一した後、旧4mm耳から頭までのサンプル最短距離は前3点5.69〜5.95mm、後4点17.57〜17.62mm。口逃げのため追加した正面カラーは3mm高く、表面から頭まで2.69mmになるが、固定穴の軸線が頭へ届かない問題自体は解消しない。従来の「現物合わせで固定」では、支持柱・受け座・ねじの荷重経路が欠ける。半径78/70/62/54、頭中心へ11mm寄せた62/54/46の計49位置も比較した。中心を寄せて殻に届く後部候補は、φ6支持柱が後脚ケースへ最大約794mm³食い込む。前・後・目・ケースを同時に扱う取付再設計が必要である。[head-attachment-candidates/comparison.json](head-attachment-candidates/comparison.json)

## カメラ：実寸から具体化した内部候補

公式OV3660資料（確認日2026-09-05）ではセンサー8×8×5.3mm、FPCを含む全長21.2mm、対角画角102度、水平85度。現行のOV2640前提20.5×12.5×5.54mm、68.7度と異なる。

出典: [Seeed OV3660仕様書](https://files.seeedstudio.com/wiki/SeeedStudio-XIAO-ESP32S3/new-res/OV3660_Camera_Module_Specification.pdf)、[公式XIAO資料](https://wiki.seeedstudio.com/xiao_esp32s3_getting_started/)。取得PDFと描画は `primary-sources/` に保存した。

元の瞳径10mmを保つには平面式ではレンズ後退4.05mm以下だが、実形状の中心には浅い凹みがある。3.8mm後退は実レイ648本中60本を遮り、**3.2mm**で648本全てが通った。可視外面2.5万点の最大差は0.0088mm。見えない内側リングの孤立片2.86mm³を明記して除去した。候補のshell/base/carrierは全て1体で閉形状、各交差0。[camera-ov3660-candidate/comparison.json](camera-ov3660-candidate/comparison.json)

XIAO本体は公式2023 STEPから、USB込み・SD無し22.782×17.780×8.030mm、SD有り24.363×17.780×8.500mmと実測した。21×17.8mmの基板寸法だけではUSBや拡張部の張り出しを落とす。STEPの開いた面は占有判定に使わず、閉じた全厚包絡を使用した。[primary-sources/xiao-step-measured/camera-removed-summary.json](primary-sources/xiao-step-measured/camera-removed-summary.json)

短FPC9.2mm以内の必要条件に絞った1305配置では、現行baseと無加工で共存する案は0だった。頭座標の修正後、chassis中心(0,45,23)を起点に、基板片側0.3mmの余裕を持つ底トレー・側面レール・非導電ストラップ穴をcamera_baseへ一体化した候補を保存した。可視キャップを保ち、base内部を約175.84mm³逃がす。FPC曲線の実長9.2mm、最小曲率半径3.316mm。候補3部品は各1連結・閉形状、頭外殻/保持具/センサー/現行ケースとの各材料交差0、基板を後ろへ35mm引き抜く141姿勢も0を確認した。

瞳とキャリアの648レイは全て通るが、全身を含む保守的な対角102度の円錐では648本中3本が口のCapへ当たる。18姿勢で同じ最下端のレイで、レンズ内のケラレと区別する。実画像は円錐でなく長方形の画角なので、全対角の有効画像範囲は実カメラでも確認する。[full-fov.json](camera-ov3660-candidate/full-fov.json)

FPC入口の正確な面・符号、現物改版、曲率の許容、アンテナ/IPX配線、USB常設プラグ、ストラップの締め付けと基板端の荷重は未確認。採用済みの印刷品として扱わない。[xiao-cradle-comparison.json](camera-ov3660-candidate/xiao-cradle-comparison.json)。初期カメラ5 STLはcamera局所座標、XIAOを含む追加3 STLはchassis座標であり、混同しない。

## 首・締結・材料・組立の残り

- 首はφ6/8、出口y−80/−75/−70/−65の8候補を作成。全て1体で閉形状。8mm孔の先端壁は丸棒12mmに対して最小2mmになる。配線候補はCabin側のφ8・曲率R25へ接続する。
- 600g×2g、68MPa、応力集中係数2.5という既存仮定では、首の最小安全率は中実3.105、壁1.6mm・40%密度2.723で、要求3を下回る。支配断面は孔の先端ではなく基部y−43.29。`4walls/40%`だけで「中実同等」と判断しない。[neck-wire-candidates/comparison.json](neck-wire-candidates/comparison.json)
- HeadTop–首89.23mm³に対する単純な頭側切削は、サンプル300,000点中651点の後向き外面を失う。TailJointはその位置を覆わない。不可視加工だと断定していない。[head-neck-cut-visibility.json](head-neck-cut-visibility.json)
- 別担当の首候補は前側y−59〜−43の幅44mm補強と実Head+0.3mmの逃げで、φ8通線、安全率3.86、HeadTop交差0まで具体化した。ただし元の首にはTailJointBlue約3282mm³、Ball約2048mm³、CabinFront約1200mm³、CabinEye約878mm³の占有重なりがあり、候補の首だけで完成とはしない。TailJointの頭側半分は中実で、首を通せる中空部ではなかった。
- 脚の細長いリンクは既存検査の中実強度と、殻+40%密度の感度を分けた。梁モデルは層間/穴周り/クリープ/ねじ緩みを表さない。tibiaの旧係数で中実約2.11、殻+40%約2.01の安全率に留まる。
- `check_screw_bosses.py` の材料充填率はボス位置の検査であり、全ねじの長さ、ドライバー経路、ナット挿入、締付けによる保持を一括保証するものではない。今回の内部腕修正ではホーン座/ケースフレーム保持を個別検査した。
- 目のホーン中心ねじは設計上アクセスが乏しく、摩擦嵌合と接着だけに依存する記述が残る。目は小荷重でも転倒時の軸方向抜け止めを実機確認する。サーボホーンの寸法/軸歯数は購入機種照合が先である。
- Cabinの一体ソリッド、Pegの6.3075mmずれ、電装室/配線通路/着脱棚は担当の [cabin.md](cabin.md) にある。元の「15%の中空だから電装が入る」という解釈を採用しない。

## 印刷と検査結果の読み方

最初の99 STLは全て閉形状だった。元の左右肘部品と任意スタンドの複数連結片は用途として別記している。「閉じている」は組立可能という意味ではない。

口逃げを加えたシャーシはCAD内では閉体でも、STL保存後の再読込でゼロ体積の2枚面が分岐し、非閉形状になった。最終統合前の実STL検査が検出した。0.001mmの簡約で解消し、体積差は+0.00303mm³、除去0.000619/追加0.003649mm³。口・支持材・挿入の再検査も合格した。`lib.export()` はSTL化したバイト列を再読込して閉形状/向き/有限正体積を確認し、不正なら例外を出して旧出力を保持する。単なる警告表示で生成成功にはしない。[chassis-stl-roundtrip.json](chassis-stl-roundtrip.json)

独立試験では、既存の `to_trimesh()` にあった `process(validate=True)` が閉じた内部空洞の面も外向きに反転する欠陥を検出した。外10mm箱から内6mm箱を引いた正体積784mm³が1216mm³へ増えていた。`validate=False` にしてManifoldの面順序を保ち、保存後体積をsourceと絶対0.01mm³＋相対1ppm以内で照合する。全生成物はこの変換で再生成する。保存は同じディレクトリの一時ファイルへ完了後に置換し、容量不足や置換失敗でも前のSTLを保つ。正常・鏡映・内部空洞・複数閉体と、欠面・空・NaN・途中書込・置換失敗を含む独立8件＋基本/実tibia3件の計11件が合格した。

ルートの `TACHIKOMA_Phase0_PETG.3mf` は現行tibiaと体積6.848%差、femurと2.097%差/最大頂点差7.596mmがある。既存26 3MFだけを見る第1次調査から取りこぼしていた1ファイルである。新たな腕/音声/coxaの生成により、関連する旧3MFも再照合が必要になる。上書きせず、元の印刷履歴と再生成候補を分ける。

`claw_mount_L` の2壁/15%という個別設定、印刷数量や旧設定の警告は機械台帳へ残した。STL読込・スライサ設定・実印刷の材料/層接着は別の確認段階である。

未解消の足接地やHead–首を検出した診断は、終了値1を維持する。`check_shin_arm_leg.py` に残る最大0.25cm³の既知残差許容は、全干渉0を保証しない。全体の実部品ブーリアンと最終ログで補う。ブーリアンのNone/NaN/負体積と、STL保存後の不正形状は正常と見なさない。

## 既購入・既印刷品を生かす順序

1. 購入サーボ/UBEC/カメラ改版を実物と照合し、頭内のケースと固定座を同時に解決する。今の頭・シャーシの追加印刷は確定寸法と支持構造が揃うまで進めない。
2. 既存外観の足・つま先を保って、候補TPU靴と根元の隠れた座を比較する。荷重・接着・横滑り・転倒での試験が先。
3. source修正済みの腕/音声は新STLを個別部品で無通電仮組みし、全挿入経路と低トルク可動を確認する。脚の本体と外観一式を付けた通電とは分ける。
4. 電源枝ごとの電流/降圧温度/最低電圧と、吊った状態のゼロ・全遷移を実測する。机上の公称トルクで連続作動を保証しない。
5. 機構・電気のゲートを満たした後に、支持下での低速1脚、4脚保持、低速歩行、外観一式の順へ進む。今回の計算だけで実機合格とはしない。

## 最終生成物での確認

`final-geometry/generate` 完了後の実STLで、腕4可動ペア1664姿勢・固定4項目は全交差0、4部品とも1閉体。口とシャーシも全交差0、下側からの挿入363姿勢0、保護リング/他支持材の確認が合格した。シャーシ実体積は54609.823339mm³、1閉体。sourceだけでなく保存後のファイルに対する結果である。[arm-joints-final-stl.json](elbow-cover-candidates/arm-joints-final-stl.json)、[mouth-chassis-final-stl.json](mouth-chassis-final-stl.json)

最終機構台帳は179ファイル（STL99、3MF27、Python50、配置JSON3）を収録した。STL99件の非閉形状は0、SHA-256を実ファイルと全件再照合して差分0。3MFの現行STL/設定照合で9件にエラーが残る。原印刷ファイルは上書きしていない。頭固定7軸は依然として殻へ当たらず、手は36組中10組の交差でNGを維持する。物理試験の最終条件一覧はsimulation担当の報告へ統合する。

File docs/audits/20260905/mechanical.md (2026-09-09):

# 機構・印刷成果物・配線の監査（2026-09-05）

**現行の足部は、TPU足裏で荷重を受けるという前提を満たしていない。**
無移動保持の時点でトゥが先に床へ触れる。既定体高115mmの後脚では、トゥとTPUの
最低高さの差が14.51mmある。体高110〜130mm・歩幅を縮めた指令でも解消しなかった。
既存の部品を捨てる根拠ではないが、現状のまま完成状態の歩行を合格とする根拠もない。

CAD・STL・既存3MF・実機は変更していない。修正したのは印刷生成時の誤材料指定と
上書き防止、配線説明、独立した診断・検証スクリプトである。

## 1. 足の支持点の不一致 — 完成状態の歩行を止める課題

体高115mm保持時の実メッシュ側面投影

現行 `foot_pad.stl`、`leg_foot_bored.stl`、`kit_assembly` のトゥ3個/脚を評価した。
床までの最小高さはメッシュ頂点の線形変換で求めており、凸包化による距離の近似はない。
IKと足位置は `sim_gait` のワークスペース射影を使った。
代表保持姿勢は、別途4×4の全変換行列による全頂点変換でも一致を確認した。

体高115mm、無移動保持での数値（床の基準は計算上の z=0）:

| 脚 | トゥ最低z | 硬い甲の最低z | TPU最低z | トゥとTPUの差 |
|---|---:|---:|---:|---:|
| 前脚 FR/FL | -1.927mm | +7.900mm | +9.357mm | 11.284mm |
| 後脚 RR/RL | -5.813mm | +4.824mm | +8.699mm | 14.512mm |

床はトゥを突き抜けないため、実機ではここから胴体姿勢・脚位置・荷重配分が変わる。
表の負のzは実機が床へそのまま沈むという予言ではない。**同じ脚の最初の接触が
TPUではない**ことを示す。甲もTPUより低いため、トゥだけを外す案では解決しない。

追加走査は体高110/115/120/125/130mm、位相360点、前後左右・斜め・旋回・複合指令を
1/6・1/3・2/3・最大に縮めたもの、SWAYだけを残したゼロ歩幅、無移動保持を含む。

- 324,020姿勢、IK失敗0。
- 接地相243,020姿勢のすべてでトゥがTPUより0.1mm以上低い。
- そのうち182,581姿勢では硬い甲もTPUより低い。
- 体高115mmの最大指令群: 最低トゥz=-13.432mm、最悪のトゥ対TPU差19.566mm。
- 体高を130mmへ上げても、保持時のトゥ対TPU差は13.936mm残る。
- SWAYを止める無移動保持でも差が残るため、歩幅縮小だけでは解決しない。

単純にパッドを局所-Z方向へ下げる幾何上の下限は、115mm保持で前脚11.51mm・
後脚15.57mm。今回の歩行範囲全体では最大26.39mmとなる。これは**安全代なしの
位置差**であり、その長さの柔らかい棒を作ればよいという設計結論ではない。
取付部、座屈、足先干渉、地上高、質量・歩容・見た目への影響を再検証する必要がある。

修正候補は、元のトゥを保存しつつ足の内側へ荷重を通す着脱式支持部品、足部の取付姿勢の
見直し、またはトゥを荷重支持部品として設計・摩擦・接着強度まで評価する方法。
見える形状や接着位置を独断で削ったり変えたりしない。

トゥ位置はリポジトリの組立座標を前提とする。元の記録では接着座り方の確度が中程度なので、
ユーザーが実際に組んだ足との照合は未完了。ただし差は0.1mm程度の公差より十分大きく、
現物合わせを理由に無条件で無害とはできない。

再現: `tools/check_toe_contact.py`、結果 `toe_contact.json`、
ログ `logs/check_toe_contact.log`。診断は未解決の先行接地を検出して終了コード1を返す。
図の再生成は `tools/render_foot_contact.py`。

## 2. 印刷成果物と生成器 — 修正済み、既印刷品の確認は残る

26個の3MF、101個のobjectを、現在の元STLと**双方向頂点距離0.02mm以内**で照合できた。
STLの頂点順序、回転、平行移動、および元キットの「100%埋込+build変換150%」も扱う。
今回の範囲では、形状の古い埋込みや材料種別の不一致は検出しなかった。

既存の `make_plates.py verify` は体積と高さだけを比較していた。同体積・同高さでも
XY形状が違う例を旧判定は見逃すため、XML参照とbuild変換を読む別の検査器
`tools/check_print_artifacts.py` に置き換えた。管理外の単発3MFも独立検査の対象にした。

確定した生成器の不具合:

- `foot_pad.3mf` の現物はプロジェクト内6番のTPUを使用する一方、生成器は1番のPLAを
  指定していた。TPUを6番へ修正し、TPUの現物テンプレートから温度・サポート設定も保持する。
- 生成器の既定出力は `outputs/print-plates` へ変更した。既存ファイルがあれば拒否し、
  意図した置換にのみ `--overwrite` を使う。既存 `hardware/stl/*.3mf` は自動上書きしない。

現物3MFの注意点:

- `PLA_Matte_Blue_1`、`PLA_Matte_Blue_2`、`PETG_Walk_4_Rest`、`foot_pad` は
  全数生成定義から部品/数量が減っている。既印刷品を外した可能性があるため、勝手に全数へ戻さない。
- **`claw_mount_L.3mf` は爪台だけのファイルではない。** 肩・上腕・前腕・爪台の7種類を
  含み、壁2・15%で保存されている。現行の腕骨格仕様の壁4・40%より低い。
  このファイル由来の印刷品がある場合は、印刷履歴を確認し、現行強度前提に当てはめない。
- 黒/赤フィラメントの実際の装着色、プリンタへの割当、印刷成功は今回確認していない。

回帰検査3件は成功。誤材料の人工的再現が拒否されること、TPU/数量/サポートを維持すること、
既存3MFのハッシュが変わらないこと、無断上書きを拒否することを確認した。
代表的な骨格プレート `PETG_Walk_3_Tibia` も一時出力先で再生成し、4個の実形状とPETG指定を照合した。
結果は `print_artifacts.json` と `logs/test_print_artifacts.log`、`logs/build_review_plate.log`。

## 3. PETGの強度 — 中実断面の成功は実印刷強度の保証ではない

既存の脚・pod_neckの応力検査は、STL内部を中実として断面二次モーメントを計算する。
現物の指定は壁4・40%充填なので、内部空隙と層方向、実材料、乾燥状態が別の未確認事項になる。
新しい `tools/check_print_strength_sensitivity.py` で、外壁と40%密度の均質コアに
分けた断面の感度を調べた。**実スライサの経路やFEAを再現するものではない。**

| 対象 | 中実の仮定 | 壁1.6mm・40%コア | 壁1.8mm・40%コア | 既存の要求 |
|---|---:|---:|---:|---:|
| tibia、55MPa仮定 | 2.110 | 2.010 | 2.057 | 安全率2以上 |
| pod_neck、68MPa仮定、Kt=2.5 | 3.088 | 2.710 | 2.791 | 安全率3以上 |

pod_neckの近似結果は要求未達。tibiaも材料や造形の小さな変動で判定が逆転する余裕しかない。
これは破断の確定判定ではなく、中実の判定を完成保証にできない根拠である。
既印刷品を保存したまま、実荷重・変位・残留変形・層間の傷を調べる必要がある。

68MPaは [Bambu PETG Translucent の公表値](https://us.store.bambulab.com/products/petg-translucent?id=42720025804936&skr=yes)
（平均68±3MPa、確認2026-09-05）。材料公表値をそのまま許容応力とすることも実機では未確認。
レポート: `strength_sensitivity.json`。診断はこの近似の要求未達に対して終了コード1を返す。

## 4. 配線の不備 — 文書は修正済み、実配線は未確認

`docs/wiring.md` にPCA9685のVCC→3.3Vがなく、「5V/GND→各モジュール」とだけ書かれていた。
PCAのVCCを5Vにつなぐと基板のSDA/SCLプルアップも5Vになる経路を避けるため、
**ESP32の3.3V→PCA2枚のVCC、サーボ用V+とは分離**と明示した。
[Adafruitの一次配線仕様](https://learn.adafruit.com/16-channel-pwm-servo-driver/pinouts)
でVCCとプルアップの関係を確認（2026-09-05）。購入品の端子表記と待機電圧は実測が必要。

ES9251 IIについては [EMAX公式](https://shop.emaxmodel.com/products/emax-es9251-ii-4g-plastic-micro-digital-servo-for-rc-model)
の4.5〜6.0V指定を確認した（2026-09-05）。これを理由にサーボバスを6V以上へ上げてよいとはならない。
[HOBBYWING公式](https://www.hobbywing.com/en/index.php/products/ubec-10a-2-6s152)
の対象UBECは10A連続/20A瞬間であり、瞬間値を連続余裕へ読み替えない（確認2026-09-05）。
購入済みサーボ個体のトルク・電流、バッテリー電圧低下時の保持力は未測定。

## 5. 既存の購入品・印刷品を生かす作業順

1. 足部改修を独立した課題として、上図と実物の接着姿勢を照合する。支持点と必要な見た目を確定してから設計する。
2. 片脚の寸法・ホーン・電圧・PWM幅を実測し、吊り支持下で荷重試験を行う。購入品を変更する判断は結果に基づく。
3. 既印刷の腕・脛・pod_neckについて、使った3MF/設定/材料と現行断面の一致を確認する。
4. 足の支持形状決定→局所形状検査→URDF接触更新→物理シミュレーション→実機で足別の接触と滑りを検証する。
5. その後に全体電流・温度・電圧降下・脚先変位を測る。先に全数再印刷や電源電圧変更を行わない。

本監査の成功したソフト検査、残るモデル前提の問題、必要な実測を分けて扱う。
過去の設計完了・全緑という記載だけでは、上記の課題を完了にはできない。

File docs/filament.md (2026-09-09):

# フィラメント購入リスト (Bambu Lab X2D 用)

**追加注文には [最新の購入・残量確認一覧](additional-purchases.md) を使う。** Amazon 履歴では PLA 赤・青・黒・灰と TPU 黒が各 1kg 配達済み。過去の白/PETG 装着記録とは別の根拠で、現在の残量は未確認。下表の推奨巻数をそのまま追加注文しない。

**2026-09-05:** 下表は8月22日版の概算を保存したもの。音声・腕・Cabinの内部修正と
不使用Head_Plate/Bottom_Capの計上修正を反映した[現行概算](audits/20260905-round2/manufacturing.md)を参照。購入済み在庫を先に照合する。
足のTPUは先行接地を満たしておらず、2gを完成版の必要量としない。

必要量は `tools/filament_calc.py` による実メッシュ体積ベースの見積り
(表面積×壁厚+インフィルの物理モデル、誤差 ±30% 想定)。
購入量は **試作・印刷失敗・色替えパージ・将来の補修** を織り込んだ推奨値。

## 必要量 (正味) と購入推奨

| 材料 / 色 | 正味必要量 | 購入推奨 | 用途 | 備考 |
|---|---|---|---|---|
| **PLA 青** | ~833g | **1kg × 2** | Cabin/Head/脚シェルの本体色 | 最大消費色。失敗許容+補修用に 2 巻。タチコマらしい青は Bambu PLA Basic の Blue 系かマットブルー。2026-07-31 shin_shell のリリーフカット再評価で +17g/セット。**2026-08-22 Head_Top_Eyecut の内殻ホロー化 (電装との共存に必須の機構逃がし, `tools/make_head_eyecut.py`) で 95→64g** — 正味合計は `tools/filament_calc.py` 2026-08-22 実行値 833g へ更新 |
| **PLA グレー** | ~189g | **1kg × 1** | 関節・砲・ディテール・足の甲 | thigh_cap / leg_foot_bored ×4 (元 Leg_Foot 加工版, ~12g) 含む |
| **PLA 黒** | ~40g | 1kg × 1 (他用途兼用) | つま先・インサート類・**指 (Arm_Left_Finger_Black_x3 ×6, 2026-07-29 固定爪化で無加工キット部品として印刷)** | 手持ちがあれば購入不要の量 |
| **PLA 白 (またはナチュラル)** | ~29g | 1kg × 1 (他用途兼用) | 目パーツ (可動眼球 eye_pod ×2 = 左右, 元キット Head_Eye_White 形状。中央目 eye_pod_camera ×1 = 固定カメラ加工版, 同形状) | **LED 透光のため低インフィルで印刷** (壁2/8%)。半透明のナチュラルが最も光る。ドット穴は黒仕上げ |
| PLA 赤 | ~4g | 購入不要でも可 | 赤ランプ ×8 | 白で印刷して赤塗装/赤マーカーでも代替可。買うなら最小量 |
| **PETG (黒 or グレー)** | ~570g | **1kg × 1** | 脚・腕骨格 (claw_mount 込み)・シャーシ・ポッドネック・バッテリークレードル・目キャリア・カメラキャリア (構造材) | 放射配置 v3 (pod_neck 20g + battery_cradle 17g) 込み。pod_neck は 2026-07-31 頭部中央寄せタスクで頭部逃がしカット (`hardware/src/make_chassis.py _head_relief_cutter()`) を追加し 22g→20g (同日 QA 再検証で `HEAD_RELIEF_PROTECT_H` を6→8mmへ再増厚+テーパー追加した後の最終値、旧報告の19gから訂正。docs/assembly.md 参照)。battery_cradle は旧報告の13gが `tools/filament_calc.py` の実測 (17g, `docs/print_manifest.md` と一致) と食い違っていたため17gへ訂正。2026-07-29 固定爪化で腕骨格が可動グリッパ (旧 palm_base/grip_slider/grip_finger) 廃止により ~115g→~55g へ軽量化 (printing.md 参照, 全体 PETG では旧 621g から -49g)。片脚試作+claw_mount 先行印刷 (接着面の現物合わせ用, printing.md 参照) のやり直し分を含めて 1kg で足りる想定。色分け不要の単色プレート (指は PLA 黒側で計上済みなので PETG 側に黒指定の例外パーツは無い) |
| **TPU 95A** | ~2g | 最小巻 (500g 等) × 1 | foot_pad ×4 (leg_foot_bored 底面の隠し接地パッド。2026-07-28 Leg_Foot 化で旧 足先チップ を置換) | ほぼ余るので他プロジェクト兼用前提 |

購入目安合計: **PLA 4-5 巻 + PETG 1 巻 + TPU 1 巻 ≈ ¥12,000〜18,000**
(ブランドにより変動。UNVERIFIED: 発注時に要確認)

## X2D での運用メモ

- **デュアルノズルの活用**: 青+グレーの 2 色プレート (Cabin まわり) を
  ノズル分担すると AMS 色替えパージを大幅節約できる
- 骨格 (PETG) は色替え不要の単色プレートにまとめる (2026-07-29 固定爪化で
  黒指定の grip_finger [PETG] は廃止済み。指 Finger_Black は PLA の
  意匠シェル側で計上されるため、PETG プレートに色替え例外は無くなった)
- 白目パーツは単独プレートで (インフィル設定が他と違うため)
- 黒/白/赤の消費は僅少なので、AMS に常設のスプールがあればそれで足りる

## 消費内訳 (上位、`tools/filament_calc.py` 出力)

| パーツ | 印刷重量目安 |
|---|---|
| Cabin_Front_Blue (青, 2026-07-28 以降無加工) | ~363g |
| Cabin_Back (青) | ~171g |
| shin_shell ×4 (青) | ~164g (2026-07-31 リリーフカット再評価でキット形状復元、旧~147gから+17g) |
| Head_Top (青, 2026-08-22 内殻ホロー化 306→52cm³) | ~64g |
| Head_Bottom (青) | ~67g |
| tibia_link ×4 (PETG) | ~152g |
| chassis (PETG, 円形ハブ v3) | ~76g |
| pod_neck + battery_cradle (PETG, v3 追加) | ~37g (pod_neck 20g + battery_cradle 17g。pod_neck は2026-07-31 頭部逃がしカット+同日QA再検証の増厚/テーパー追加で22g→20gへ。battery_cradleは旧13g表記の誤りを17gへ訂正) |
| coxa_bracket ×4 (PETG, 標準2+ミラー2) | ~124g |
| femur_link ×4 (PETG, 標準2+ミラー2) | ~114g |
| 腕骨格一式 ×2腕 (PETG, shoulder_bracket+upper_arm+forearm+claw_mount) | ~55g |

(数値は壁2/インフィル6-8% (シェル)、壁4/25-40% (骨格) 前提)

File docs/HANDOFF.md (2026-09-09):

# HANDOFF — 引き継ぎ文書 (2026-07-31 作成 / 2026-09-05 再監査)

**先に読む最新結果:** [2026-09-05 第2次監査](audits/20260905-round2/README.md)。
頭部サーボケースの収納、Cabin接合・電装室、腕・音声の実体干渉も追加検査し、内部逃げ・配置・制御・STL変換を修正した。
本文の過去の「設計完了」「物理シムで歩行実証済み」は、実機の組立・連続歩行の合格を意味しない。
この文書には過去時点の完了記録と、現在の採用途中の検査結果を併記している。現在の基準は第2次監査と作業中の各構成の根拠であり、過去の全グリーン記録を新構成の合格へ読み替えない。第2次監査の保存結果は **14 PASS / 8 FAIL / 1 UNVERIFIED** で、機械・電源・実起動・材料別接触には未確認事項が残る。
トゥの組立倍率を印刷指定150%へ訂正すると、硬いトゥが現TPU足裏より前脚18.102mm/後脚22.034mm先行する。足裏支持の修正が必要。
装飾ガードは大腿81%/脛78%が支持殻へ埋まり、受け座だけ切っても挿入できない。固定爪・指飾りにも未確認の嵌合交差がある。RV-16/RV-17を解決するまで旧接着手順を確定扱いしない。
制御・検証コードは修正済み。既存の購入品・印刷物は保持し、実物の版・材質・寸法で再利用を判断する。

前任エージェント (Claude) から後任 (Codex 等) への完全な引き継ぎ。**この文書は
セッション文脈ゼロで読んで作業再開できることを目標に書かれている。** 運用規約の
要約はリポジトリ直下の `AGENTS.md`、設計の全体像は `README.md` を参照。

目次: §1 現在地 / §2 リポジトリ地図 / §3 検証体系 / §4 設計の鉄則 /
§5 物理フェーズ・ロードマップ / §6 未解決・保留事項 / §7 外部連携 /
§8 ユーザーの作業スタイル / 付録 A 落とし穴集 (基礎54 + 追加55-59)

---

## §1 現在地サマリ

- **過去の設計完了記録** (2026-07-31、履歴)。設計タスク #1〜#33 が当時の
  スナップショットで完了し、検証は**全グリーン・既知 NG ゼロ** (§3 の 12
  コマンドすべて PASS)と記録されていた。この記録は現在の構成・監査結果を示さない。
- **現在の採用途中の記録** (2026-09-05)。第2次監査は14 PASS / 8 FAIL / 1
  UNVERIFIED。解決済みの制御修正と、未解決の収納・干渉・足裏支持・材料/実機確認を
  分けて扱い、検査コマンドの要求結果を緩めない。
- **印刷優先の電装占有補助** (2026-09-05): `tools/print_first_components.py` は
  `export_urdf.base_link_electronics_items` を呼ばず、電池候補の寸法・質量・基準位置を
  引数で受け、`check_audio.py` の実ポケット候補を Cannon ローカルから `base_link` へ
  一度だけ変換する。`get_print_first_component_bundle()` / `get_print_first_component_meshes()`
  は同じ記録からbase座標の電池box・マイクbox・スピーカー円柱を返す（スピーカーの局所
  envelopeは [20,5,20] mm、軸はY）。マイク/スピーカーの対象部品寸法と収納は
  UNVERIFIED、配線等97 gの残差は固体箱にしない。このモジュールと
  `hardware/src/config.py` のSHA-256を印刷優先マニフェストの `sources`、および次回
  凍結時の入力/source hashへ含める。
- **過去の物理シミュレーション記録（現行制御の前進証拠として使用しない）**: `tools/sim_physics.py` (MuJoCo) で
  重力・接触・摩擦・旧DS3218想定トルク (1.96N·m) 込みの 13 秒シーケンス
  (静定→前進→旋回→停止) を転倒なしで完走 (max |roll| 6.4° / |pitch| 2.7°)。
  動画 `docs/vis_physics_walk.mp4`、数値 `docs/physics_walk_metrics.json`
- 無滑り時の接地区間速度は **25mm/s** (`MAX_STEP/(DUTY*CYCLE_T)=30/(0.75*1.6)`)。
  旧18.75mm/sは接地率DUTYを落とした計算。実測速度とは区別する。
- 直近の主要な設計確定 (いずれもユーザー決定済み・変更しないこと):
  - 頭部位置 `ARM_MOUNT_HUB_Y = 11.0mm` — 完全中央 (0mm) は腕肩サーボ×前脚サーボの
    物理衝突で不可能と実測確定。11.0 は「全チェッカー緑を保てる最中央値」
    (binding constraint は肩 MICRO ボス×STD ケース開口の壁肉厚 ≥0.3mm)
  - 砲身 (Mouth_Cannon) は水平から **18° 下向き** (`MOUTH_CANNON_ROT_X_DEG=-18.0`)。
    実物写真準拠。角度はこの 1 定数で調整可
  - 脛シェル `shin_rotz=0` (装飾ドット面が放射外向き ×4 脚、実物写真準拠)。
    リリーフカットは `LOOP_RELIEF` のみ残存 (ループ意匠は内部キャビティと構造的に
    両立不能なため切除 — 外観は実物と同じ「外から見えない」なので影響なし)
  - **膝はメカ剥き出しで確定** (ユーザー決定。Leg_KneeJoint_Grey は不使用のまま、
    新規カバー形状も作らない)
  - 腕×脚連成クランプ: 同側前脚ヨー >20° (`ARM_LEG_YAW_GATE_DEG`) で腕ヨーを
    -15° へ自動退避。2026-09-05のホスト検査で得た発火率0〜12.7%は履歴値であり、
    実機の連続歩行を保証しない
  - **元モデル (TACHIKOMA.3mf) の著作権はユーザー本人に帰属** (2026-07-31 本人確認)。
    モデル利用規約系の注意書きは docs から削除済み

## §2 リポジトリ地図

```
hardware/src/    コード CAD (Python/trimesh/manifold3d, 単位 mm)
  config.py        ★寸法の唯一の正 (リンク長・関節リミット・配置定数)。変更はここだけで全連動
  build_all.py     全カスタム STL の再生成エントリポイント
  make_*.py        各サブシステムの生成 (leg/arm/head/chassis/eye/audio/camera/shell_mod)
hardware/stl/    カスタム STL 41 個 (★150% スケール済み — スライサでの拡大不要。2026-08-19 eye_pod_camera の shell/base 分割で 39→41)
model/           キット元 STL 58 個 (★100% のまま — 印刷時はスライサで 150% 指定必須)
tools/           チェッカー群 (§3)・export_urdf.py・sim_physics.py・make_visuals.py・
                 kit_assembly.py + data/kit_assembly_{front,rear}.json (意匠パーツ配置 DB)
firmware/        PlatformIO (ESP32)。config.h / gait.h / arms.h / eyes.h / audio.h / web_ui.h
hardware/urdf/   フル見た目版 URDF 一式 (23 リンク / 可動 20 関節 / メートル単位 / 総質量 2.78kg [2026-08-22 Head_Top ホロー化後])
docs/            全ドキュメント (AGENTS.md のドキュメントマップ参照)
```

- `hardware/urdf/` の閲覧: `.venv/bin/yourdfpy hardware/urdf/tachikoma.urdf`
  (`--animate` で全関節アニメ、`-c ...` で任意姿勢 — 立位姿勢ベクトルは docs/urdf.md)
- 3MF 一次情報: `Downloads/TACHIKOMA.3mf` — `Metadata/model_settings.config` の
  source_offset (組立座標フォレンジクス) と `Auxiliaries/.thumbnails/thumbnail_middle.png`
  (完成写真) が配置検証の一次情報

## §3 検証体系

コマンドと期待結果は `AGENTS.md` の「検証の掟」ブロックが正。要点:

| チェッカー | 見ているもの |
|---|---|
| check_leg_assembly | 脚の全姿勢干渉・隣接脚・接地高さ (worst z +0.05mm)・トゥ嵌合 |
| check_screw_bosses | 全ネジボスの環状肉厚 (fill ≥70%)・ケース開口とのクリアランス |
| sim_gait | IK/FK 往復誤差 0・歩容 41,600 姿勢 IK 失敗 0・静的安定 +10.9mm (実重心 CG_XY 基準)・静的トルク全域 18.5kgf·cm (3/4 点支持静力学)・firmware 定数 regex 突合 |
| check_leg_link_strength | tibia/femur の断面応力スキャン (SF ≥2.0, 荷重 3.8kgf 動的込み)。tibia 膝ネック SF 2.1 |
| check_arm | 腕の取付/干渉/トルク/砲身スイープ [8]・Ball/Neck/Cannon×シェル [1d] |
| check_eye / check_audio / check_camera | 目モジュール収容 / 音声クレードル肉厚・ボア連通 / カメラ FOV 遮蔽 0% (8 姿勢) |
| check_shin_arm_leg | 脛シェル×骨格/隣接脚/腕 (到達可能集合基準 + クランプ再現 + 発火率 [C-duty]) |
| check_head_pod_clearance | 頭球×pod_neck クリアランス ≥2mm (hub_y スイープ) |
| check_pod_neck_strength | pod_neck 片持ち梁の全区間 σ(y) スキャン (Kt=2.5 込み安全率 ≥3、現状 3.23) |
| check_urdf | URDF 380 項目 (運動学突合・FK 0mm 一致・慣性・メッシュ被覆 126 パーツ) |

**回帰の掟**: 形状・配置・firmware 定数を 1 つでも変えたら、`build_all.py` →
`export_urdf.py` → 全チェッカー → `pio run` まで回して全緑を確認してから完了と呼ぶ。
チェッカー自体の「期待値がトートロジー (生成コードと同じ値を複製) になっていないか」も
レビュー対象 (実例は付録 A #31)。

## §4 設計の鉄則 (背景と実例)

1. **見える形状は元キット準拠**: 独自造形の目・腕は 2 度ユーザーに棄却された (付録 #27/#29)。
   準拠の型は (a) そのまま印刷 (b) 中抜き/内部加工して被せ (c) 正規化して機構に取込، の 3 つ。
   誤って「未使用」と断定して元形状を削るのは鉄則違反 (#49 で実際に発生し復元)
2. **0.1mm 精度・実メッシュ検証**: 手計算・目視は端点しか見ず中間で外す (#10)。
   ブーリアン/レイキャスト/signed_distance で数値化する
3. **config.py 一元化**: firmware・チェッカー・docs へ複製された定数は必ず drift した
   (ARM_REACH_MM #31、HIP_DROP 5 ファイル散在 #40、literal 12 が 8 ファイル散在)。
   消費側は config.py 参照 or config.h regex 実読
4. **UNVERIFIED 規律**: 価格・寸法・物性など未確認値は「UNVERIFIED + 相場/文献値 + 確認日」で
   記録。「確認済み」と書いてよいのは実出力・実測・実ページ取得の証拠があるときだけ
5. **ガードは 2 段 (target + cur_)**: スルーレートで軸ごとに到達時刻が違うため、
   目標側だけのクランプは遷移中に必ず破れる (#16 — 数値再現済み)。重畳 (wave 等) →
   クランプ → スルーレートの順序も固定
6. **到達可能集合基準**: gait.h のワークスペース射影 (D_KNEE_MIN/MAX) が出力できない姿勢は
   実機で発生しない — その姿勢だけで起きる干渉は「実害なし」と分類してよい
   (`pk_reachable()` が厳密判定)。ただし (a) firmware に歩容非経由の関節指令経路を
   追加したらこの前提は崩れる、(b) URDF を直接駆動するシミュレータでは適用外
7. **レンダ証拠は新規プロセス + mtime 確認**: `_MESH_CACHE` の stale 画像で
   「修正確認済み」と誤報した実害あり (before/after が同一 MD5 だった)

## §5 物理フェーズ・ロードマップ (次にやること、この順)

1. **部品表の確認**: `docs/shopping.md` の **D-1「一括調達候補」** を確認する。
   注意: (a) 価格の多くはJS描画で自動検証できないため、採用判断前に画面で確認する、
   (b) DS3218MG/LD-20MGは旧構成・比較候補の履歴であり、現行採用を意味しない、
   (c) 現行print-firstのLD-220は候補値のまま、実測前はNo-Goとする、
   (d) D-2表の例外5件は個別条件を確認する
2. **サーボ実測** (`docs/assembly.md` §0): 届いたサーボ・ホーンをノギスで実測 →
   `hardware/src/config.py` の `[要実測]` タグ付き定数を更新
3. **再生成 + 全検証**: `build_all.py` + `tools/make_head_eyecut.py` → §3 全コマンド緑
4. **印刷**: `docs/print-first.md` と `docs/print-first-manifest.md` の
   **Go/No-Go 5 フェーズを厳守** —
   Phase 0 (テスト印刷) → Phase 1 (片脚ベンチ・**1.2kg リフト試験合格が必須ゲート**) →
   Phase 2 以降 (全数)。**例外として、サーボ寸法に依存しない大物キットシェル
   (Cabin_Front/Back・装飾類, `model/*.stl` を 150% 指定) はいつでも先行印刷可**。
   本番設計必要数は56個（A=31、B=25）、Cの条件付き新規脛殻は4個で別枠、LD適合治具3種各1は非本番。
   いずれも今印刷可数0から解放し、実物ゲート後に進める。TPU (foot_pad) は AMS 不可・
   バイパス給紙+メインノズル限定 (shopping.md B-3)
5. **組立**: `docs/assembly.md` (§ 順)。配線は `docs/wiring.md`
6. **音声/カメラ**: `docs/voice.md` (印刷前に INMP441 基板とスピーカー厚の実測を忘れず —
   print_manifest Phase 4 の注意)

## §6 未解決・保留事項

- **Head_Insert_Black ×4 のうち 2 個の配置が未確定** (`tools/data/kit_assembly_front.json`
  の unresolved リスト参照)。3MF 側に座標情報が無く復元不能。**ユーザーが実物フィギュアを
  所有しており、頭部の写真提供を依頼済み (回答待ち)** — 写真が来たら配置を確定し
  robot_meshes/URDF に反映する。実機組立には影響なし (組立時に現物合わせで貼る)
- **直前の中断依頼**: ユーザーが「Bambu Studio を起動して印刷パーツのデータを読み込んで」と
  依頼した直後に本引き継ぎへ切り替わった。アプリは BambuStudio.app の存在を確認済み。
  再開する場合の注意: `model/*.stl` は 100% なので**スライサで 150% 指定必須**、
  `hardware/stl/*.stl` は 150% 済みでそのまま。§5-4 の Go/No-Go を尊重し、
  先行印刷は大物キットシェルに限ること (骨格はサーボ実測が先)
- **ESP32 DevKit の恒久マウント位置 (2026-08-22, ユーザー判断待ち)**:
  Head_Top 実占有ボクセル場での網羅探索 (フラット 2 方位×ピン上下+縦置き 4 面
  ×位置全域, 外皮 2.5mm+クリア 1.5mm) で**頭内は全姿勢不成立**と確定
  (`hardware/src/config.py` ESP32_SLOT コメント参照)。候補は
  ①ポッド (Cabin_Front) 内ベイ化 — ただし「Cabin_Front 無加工」方針
  (`docs/wiring.md` 悉皆確認 #10) の転換が必要 (ベイ加工自体はポッド自身
  基準なので同 #10 の反対理由=位置基準の不確実性には非依存)、
  ②後方デッキ縦置き (可視領域 — 意匠判断必要)、③小型ボードへの変更。
  歩行実験は頭シェル未装着のためテープ留めで支障なし
- **主な UNVERIFIED** (実物が来ないと確定しない系):
  サーボ実寸 (`config.py [要実測]`) / 印刷後のはめあい / 実重量 (見積り ±30%) /
  XIAO ESP32S3 Sense のセンサー (現行出荷は OV3660 — FOV/EFL は OV2640 前提のため実測要) /
  URDF 慣性 (均質密度仮定) / PETG 曲げ強度 70MPa (文献値) / Ball↔Neck の実接触様式

### §6.5 2026-09-04 全体レビューで残った要判断・要実測 (システム/機構/電装監査)

> **現行判断の境界（2026-09-08）:** DS3218、LD-20MG、旧トルク値、旧toe値、7.4V給電は
> 過去計算・比較候補であり、現行構成の採用根拠ではない。LD-220の寸法・トルク・電流は候補値で、
> 対象個体の実測と6Vベンチ確認が終わるまでNo-Goとする。現行の印刷順序と候補部品は
> [print-first](print-first.md) と[第2次監査](audits/20260905-round2/README.md)を参照する。

- **股ピッチトルク余裕ゼロ** (S-02, 2026-09-04のホスト計算): 全域最悪 18.5kgf·cm vs
  旧DS3218の比較値 ~18@6V/20@6.8V。L-02で対象個体を6V実測し、No-Goなら低トルク歩容・荷重低減・
  実測適合品を再設計する。**未確認サーボへの7.4V給電はNo-Go**で、旧案を現行手順に戻さない。
- **重心 y=-39mm** (S-01): Cabin 534g が主因で動かせない。歩容側で吸収 (STANCE_OFF_Y -30 / 後脚 SWAY 40)。
  I-01 の実測重心で `config.py CG_XY` を更新し sim_gait [4] を再実行
- **UBEC 10A 連続定格 vs 歩行 9〜14A 級見積り** (S-03): L-10 でクランプ実測 → EL-09 で 15〜20A 級への変更を判断
- **装飾トゥが foot_pad より最大 11mm 深く出る姿勢がある** (S-04, 2026-09-04の旧計算値
  -11.35mm): 接地力を細いトゥが受ける可能性がある。現行print-firstのTPU靴候補を1個だけ
  実装し、L-02/L-10で接地・保持・荷重を確認してからtrim/体高下限を判断する。
- **PETG 脚の撓み+ホーンガタ** (S-05): 弱軸 11mm/強軸 3.5mm + バックラッシュ 4〜8mm の足先誤差見積り。マージン +10.9mm
  は名目値で、実機では体高・歩幅を落として開始 (I-02)
- **アイドル発熱** (S-07): firmware に無指令時の脱力/休止姿勢が無い (低電圧カットのみ) → EL-10
- **sim_physics の metrics/help 文言不一致・関節トルク飽和未計測** (S-08/S-10) → I-08
- **ホーン形状 HORN_* は未実測** (M-08): 実ホーンが大きいとネック増厚部が更に削れる → P-03 でホーン実測後に
  `check_leg_link_strength.py` を再実行

## §7 外部連携

- **友人への Isaac Sim 配布**: `tachikoma_urdf_20260822.zip` (リポジトリ直下, 14MB)。
  **`config.py` の形状定数を変えたら ZIP は自動更新されない — 手動再生成必須**
  (手順は `docs/urdf.md`「配布用 ZIP の再生成について」)。Isaac 側の注意 (PD ゲインは
  URDF 外・Merge Fixed Joints・シム内自己接触は許容仕様) も docs/urdf.md に記載済み
- **音声会話パイプライン**: ESP32 (WS /audio) ↔ `tools/voice_bridge.py` (Mac 上) ↔
  whisper/Claude/ElevenLabs。API キーは環境変数のみ (ハードコード禁止)。
  iPhone テザリングは「互換性を最大にする」ON が必須 (2.4GHz 化)
- **権利**: 元モデルはユーザー本人の著作物。`docs/voice.md` §6 の声優ボイスクローン注意は
  **別件 (声の権利は声優本人のもの) なので削除しないこと**

## §8 ユーザーの作業スタイル (重要)

- 日本語で応対。コード・パス・識別子は原文維持
- **一次情報 + 確認日**: 価格・仕様・鮮度依存情報は必ず出典と確認日を付ける。不明は UNVERIFIED
- **実測・実出力で示す**: 「動くはず」「確認済み」だけの完了報告は受け入れられない。
  チェッカーの実出力・レンダ画像・数値を添える
- **実物フィギュアの写真が最終的な正**: ユーザーは組立済み実物を所有。配置・向きの疑義は
  写真を依頼すると決定的な一次情報が得られる (脚装飾の向き・砲身角度はこれで確定した)
- **敵対的検証を歓迎**: 自分の実装を疑う独立検証で major 指摘が出る度に品質が上がってきた。
  誤指摘は根拠付きで却下してよい (実例: 検証側が古い中間値を使った誤指摘を証明付きで棄却)
- **未達の正直な報告を評価**: 物理シムの「0.3m 目標未達 (歩容仕様上の上限)」のような
  正直な報告が信頼につながっている。数字を作らない

---

## 付録 A: 設計の落とし穴集（基礎54項目 + 追加55-59）

再発しやすい失敗と回避策。基礎54項目に、物理シミュレーション・生成順・意匠シェルの
追加55-59を続けて掲載する。元は前任エージェントのメモリにあったものを全量移植した。
(#番号は発見順。関連チェッカーに恒久化済みのものも多いが、**新規設計時に同じ推論ミスを
繰り返さない**ためのカタログとして残す)

1. **スプロール立位では股ピッチが大きく負になるのが正常** (体高115で約-21°、掃引全域で-45°まで)。リミットを「見た目の常識」で-20°に絞ると歩容IKが全滅する。
2. **膝サーボ角の規約が2通り混在しやすい**: firmware は femur 相対角。干渉チェッカーを絶対角で書くと過酷すぎる姿勢を検査してしまう (check_leg_assembly は firmware 規約に統一済み)。
3. **遊脚時に膝が最も折れる**: 接地時でなく足上げ (STEP_H) 時に膝リミットへ達する。体高最小値はここで決まる。
4. **併進+旋回の同時指令で合成歩幅が上限超過**: 歩幅ベクトルのノルムクランプが必須 (gait.h 実装済み)。
5. **tibia 上部構造は膝±45°回転で femur 側に刺さる**: 旧解は左右対称の 45°ウェッジ面取りだったが、femur は膝軸の股側 (-X) にしか無く、+X 側まで削った結果ネックが 11mm² (SF 0.1) に痩せていた (2026-09-04 M-01)。現在は femur 側障害物 (箱枠+ウェブ) の ±47° 回転掃引領域を数値的に減算し、外側 3mm 増厚 (make_leg.py `_femur_knee_sweep`)。**幾何だけでなく断面応力も見る** (`check_leg_link_strength.py`)。
6. 元モデルの小パーツはブーリアン加工に耐えない (φ18穴で崩壊)。装飾は接着対応にする。
7. **干渉チェックにサーボ実体を忘れるとケース貫通を全部見落とす**: STD サーボはタブ下 28.2mm が反対側へ突き出る。チェッカーはサーボダミー (実寸) を合体させて検査する。
8. **ブーリアンの順序バグ 2 種**: (a) ポケット減算後に正形状を足すとポケットが埋まる → 正形状を全合成してから負形状を最後にまとめて引く。(b) 面取り後にビームを足すと掃引域に角が残る。
9. **薄板へのサーボポケット素通し**: タブビスの肉がゼロになる。台座ボスを盛ってから引く (check_screw_bosses が実測)。
10. 手計算の干渉判定は端点だけ見て中間点を見落とす。必ず数値ブーリアンで裏取り。
11. フィラメント見積りは「体積×充填率」だと大型ソリッドで過大評価。表面積×壁厚+インフィルの物理モデルを使う (tools/filament_calc.py)。
12. **マウント穴は「ポケット開口と重ならないか」まで見る**: 回転配置の開口は角が回る。穴位置は回転後矩形の4隅で照合し、最後は実メッシュ contains で裏取り。
13. **ミラー対称ペイロード (両腕) は互いに衝突する**: 単体安全でもミラーモードで両手が中心線へ同時に寄る。重畳→クランプ→スルーレートの順を固定。
14. 粗い作業域近似 (円柱コリドー) は保守的すぎて成立解を潰すことがある。粗近似のままなら docs にその旨明記。
15. **回転駆動の軸方向は「何の座標を変えたいか」から逆算して検証**: 回転では回転軸方向の座標は変わらない (グリッパ駆動不能バグの根本原因)。
16. **ソフトリミットを目標角だけで評価しない**: スルーレート追従中は先着軸が「まだ来ていない姿勢」を根拠に過大角を許される。target と cur_ の両方で評価。
17. **実物のリファレンスを最初に確認する**: キャラクターものは機能設計の前にシルエット決定要素 (付け根位置・プロポーション) を実物/設定画で固定する (腕マウント全面再設計の教訓)。
18. 無限円柱で脚をモデル化すると過保守。高さ帯別 (コクサ/大腿/脛/足元) にモデル化する。
19. **lib ヘルパーを「材の向きが逆」の部品で再実装すると符号ミスが混入**: 負形状の z 範囲を 1 個ずつ書き出して材側にあるか確認。チェッカーのプローブ点は代表 1 点にしない。
20. **幾何が正しくても「組立順」が物理的に実行可能かを別途検証**: ドライバーの進入経路まで含めて手順を追う (密閉ポッドの中心ビスは物理的に締められなかった)。
21. **ファーム内の同名変数は「意味」で照合**: vx/vy の取り違え (このプロジェクトは +Y が前)。速度系引数は意味名 (vfwd 等) にする。
22. **「顔」パーツは造形の意味論まで実物に合わせる**: 機構が同じでも見た目の解釈を誤ると別物になる。
23. **matplotlib 3D はコレクション単位の平均深度で前後合成**: 近接メッシュは 1 つの Poly3DCollection に結合して面単位 zsort。
24. **[要実測] タグの値を設計前提にする前に、手元にモデルがあるなら先に測る**: 仮定値ベースのチェックは形状と無関係に OK を返し続ける。
25. **性能主張の式は「実際に動く点」の半径で立てる**: 一度は独立した数値シミュレーションで裏取り。
26. **放射状マウントの「尻尾」は中心で収束する**: 開口側だけのチェックは盲点。裏側の尾部間距離も実測。
27. **「顔」パーツは独自造形せず元キット形状を機構側へ取り込む**: 2 回の独自造形が 2 回棄却された。元メッシュの正規化流用をまず検討。
28. **輸入メッシュとのブーリアンは STL 往復で非 watertight になりやすい**: Manifold.simplify(0.01) で解決。trimesh の process 自体が壊すこともある (raw 再構築フォールバック)。
29. **「元パーツベース」は方針として最初に確定させる**: 全パーツを実測してから設計する。キットの左右非対称のような発見がある。
30. **可動化した元パーツ被せには関節の逃がしセクタが必ず要る**: 実リンクメッシュの回転ブーリアン (複数角度) で干渉 0 を検証。
31. **firmware へ複写した幾何定数は必ず drift する**: 検証スクリプトは config.h を実ファイル regex 読取で取得し実寸と突合。「firmware 挙動の再現」(複製定数) と「物理量の評価」(実寸) は別変数で持つ — 同一変数だと恒等式になり検査にならない。
32. **輸入メッシュ×箱ブーリアンは殻を非連結化する** (watertight でも別ボディに割れる): 負形状は必要範囲に限定 + 生成側 decompose() で最大連結成分のみ + 検証側で split()==1 を恒久チェック。
33. **完成図を見ずに部品名から解剖を推測しない**: Cabin は背中のポッド、前面の球体が頭 (2 段階のユーザー指摘で発覚)。スケールは全パーツ一律 ×1.5 のみ (部分リサイズ禁止)。
34. **統合基板はキットのハブ部品寸法に合わせて最初から設計**: 足先位置は STANCE_R で維持できる。移設系は隣接サブシステムへの副作用検査までがセット。
35. **trimesh の鏡映 (負行列) を boolean に入れると偽陰性/NaN**: ミラー形状は manifold3d の .mirror() で STL 出力するか座標符号反転で直接生成。trimesh 側の鏡映は描画専用。
36. **回転対称の同一脚 4 本は取付間隔 ≥90° 専用**: 45° ペア配置では対角脚をミラー版 (_m) にして張り出しを逃がす + 2 段ヨークランプ。
37. **干渉検査は「サーボ空間全域」と「IK 到達域」を区別**: IK が原理的に出力しない姿勢は運用で起きない。手ポーズ/校正時の注意は docs に明記して線引き。
38. **公式フィギュアの下面が配置の正**: フリクションクランプ関節に固定角は存在しない。真値は完成写真の実測から。シェル配置は意匠特徴の実測方位で必ず照合。
39. **非対称放射配置の歩容は (スタンス角, SWAY, LEAD) の連成調整**: パラメータスキャンで解く。副作用 (リーチ超過・内側ヨー増) の常時突合を sim に組み込む。
40. **「残す肉厚」は切削式から導出して書く**: 内腔寸法は `H - wall - flange` のような残厚導出式で。取付ボルト座面はレイキャストで実測プローブ。
41. **円筒インサートの薄肉と回転位置**: スロット切削後の残リブ厚を数値検証。円形ポケット部品にはキー突起で誤挿入を物理的に防ぐ。貫通穴の縁のレイキャスト肉厚 0 は測定アーチファクト (開口境界を除外)。
42. **音声ストリーミングの双方向流量は両端で契約**: 送信側に実時間ペーシング、終端シグナルは try/finally で保証、再接続時は状態再送。AsyncTCP はコア分離。
43. **iPhone テザリングは既定 5GHz (iPhone 12+)**: ESP32-WROOM は 2.4GHz 専用で無言で失敗。「互換性を最大にする」ON を手順の最初に。
44. **3MF の Metadata/model_settings.config に元アセンブリ座標が残っている**: source_offset の単純加算で相対配置が復元できる — 組立フォレンジクスの正攻法。ただし同一 source_object_id クラスタ内のみ有効。
45. **±40° 移設後の腕相互クランプはデッドコード化に注意**: マウント方位 > リミットだと横変位クランプが常時フロア。移設系タスクは「空いた/塞がった場所」の再検査までがセット。
46. **フォレンジクス finding も敵対検証してから設計へ反映**: 「touch すべきペアで gap 0」がメソッド妥当性の裏付けであり、非接触ペアの値は独立検算必須 (誤値の実例あり)。
47. **「見える/使える」系の検証は必ず全アセンブリを対象に**: 部分メッシュ検証は自己遮蔽しか見えない。カメラ FOV 80% 遮蔽の見落としが実例 (現在は 8 姿勢全アセンブリ掃引を恒久化)。
48. **ミラー脚に載る装飾はフィット行列もミラーする**: diag(1,-1,1,1)+invert() の後適用で厳密同値。「_m 版には _m 用の装飾配置」をチェックリスト化。
49. **等分仮定や「らしい」配置で妥協する前に取付フィーチャーを個別実測**: トゥのスタブは非等間隔だった。装飾の一部を「未使用」と誤断定して元形状を削るのは鉄則違反。
50. **接地校正は SWAY 込みの実歩容ロジックで二分探索**: IK 用実効長 (TIBIA_LEN_GAIT=155.98) と物理長 (135) は別定数で持つ。
51. **ゴースト変換の「法線の回し忘れ」はバグクラス**: 方向ベクトルも位置と同じ変換連鎖を通す。パーツのローカル軸は Z とは限らない。回転対称部品のロールは写真照合で確定。
52. **写真照合は「特徴の同定」から間違える**: まず「そのピクセルはどのパーツか」を周辺特徴で同定。物理チェーンの露出量は調整パラメータではなく嵌合実寸の従属量。
53. **準対称形状の 180° 反転は適合指標に映らない (flip-blindness)**: シーム/リング一致で向きを確定しない。非対称フィーチャーの分布と写真で判定。反転仮説テストを監査の標準項目に。
54. **カンチレバー梁の強度は「断面係数最小の一点」では代表できない**: σ(y)=M(y)/Z(y) を全区間スキャンして最大値を取る (check_pod_neck_strength.py に恒久化)。真の最弱点はレバーアーム支配で基部側にあった。

追加 (物理シミュレーション関連, 2026-07-31):

55. **PyBullet は本機 (macOS SDK 26) でビルド不能** (同梱 zlib の K&R 記法非互換、wheel も無し)。物理シムは MuJoCo (`.venv` 導入済み) を使う。
56. **MuJoCo の安定化**: 陽解法 Euler + damping 0 は立位だけで発振転倒する。implicitfast 積分 + 全関節 armature 0.001 / damping 0.02 で解決 (tools/sim_physics.py 参照)。
57. **STL 往復は頂点順序非決定**: メッシュ同一性の比較は頂点インデックスやソート比較ではなく三角形コーナー点群の KDTree 最近傍で行う。

追加 (2026-08-21/22):

58. **「カット→後から追加」順のブーリアンは浮遊島を黙って生む**: chassis の旧 ESP32 ボスが後脚開口上の空中島として出力された実例 (スライサ上でユーザーが発見)。export する全部品に「連結成分数 = 期待値」検算を置く (chassis() 末尾 assert / make_head の decompose-keep-largest)。取付ボスの検証は「ボス直下の母材」まで見る。
59. **キット彫刻の中実性はシェルごとに実測してから電装を計画する** (Head_Bottom [#55 事例] に続き Head_Top でも再発): Head_Top は 306cm³ のほぼ中実彫刻で、プレート上 z≈10-14 の「床」が脚/腕サーボケース・タブビス頭・PCA 基板と全面干渉していた (実ブーリアンで各 5.5cm³ ×4 など) — 「シェル内は中空」という無検証の前提で電装配置 (2 段スタック・ESP32 移設案) が積み上がっていた。対処は `tools/make_head_eyecut.py` v2 の内殻ホロー (フラッドフィルで外部到達面のみ保護 → 3.2mm 侵食 → marching cubes カッター。z 柱充填は座グリ/顔ポケットまで閉じて外皮を突き破るので不可) + スカートノッチ + 恒常検算 [1]-[7]。教訓: 意匠シェルの下に置く電装は「シェル実メッシュの占有ボクセル場」で配置成立性を先に検査する (解析近似や目測の空間感覚は殻形状では大きく外れる)。

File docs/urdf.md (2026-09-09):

# URDF と物理シミュレーション

`hardware/urdf/` は、現在の形状と取付座標をシミュレータへ渡す生成物です。**組立可能性や実機歩行の証明ではありません。** 2026-09-05 の第2次監査では、実部品の交差、サーボ収納不足、硬いトゥの先行接地を検出しました。自己衝突を無効にした歩行結果だけで、製作可能と判断しないでください。監査の条件と結果は [第2次の物理監査](audits/20260905-round2/simulation.md) を参照してください。

`tools/export_urdf.py` が `hardware/src/config.py`、`tools/kit_assembly.py` の組立変換、STL、`tools/make_visuals.py` の関節式から生成します。URDF は直接編集せず、原因となる入力を修正して再生成します。

個別入力が空、非有限値、非閉殻、面向き不整合、総体積が正でない場合は生成を中断します。複数の閉殻や空洞の負向き内壁を、全て正体積の部品へ変えてはいけません。出力一式は一時フォルダで完成してから交換し、生成失敗時は既存のURDF・メッシュ・履歴画像を保持します。CAD生成、URDF生成、検証の順に実行してください。

```sh
.venv/bin/python tools/export_urdf.py
.venv/bin/python tools/check_urdf.py
.venv/bin/python tools/render_urdf_compare.py --output-dir /tmp/tachikoma-urdf-preview
```

出力は次のとおりです。

- `tachikoma.urdf`: m、kg、rad の SI 単位。20可動関節と2固定関節、23リンク。
- `meshes/*.stl`: メートルへ変換済みの表示・衝突メッシュ。`mesh scale` で重ねて拡大しないでください。
- `parts_manifest.json`: 取り込んだ表示パーツの一覧。サーボの箱近似質量など、表示しない質量項目は別です。
- `render_urdf_stand.png` / `render_ref_stand.png`: 同一視点の FK 比較画像。上の例では `/tmp/tachikoma-urdf-preview/` に保存します。既存の履歴画像を残し、入力変更後の画像は別の保存先へ生成してください。

## 座標と停止姿勢

`base_link` の原点は股ヨー軸の水平面、XY原点はシャーシ中心です。+X は機体右、+Y は前、+Z は上です。シャーシ下面は原点より `HIP_DROP` 上にあります。

`BODY_H_DEF=115mm` は歩容の足先目標に使う高さであり、実形状の床面から股軸までが必ず115mmになるという意味ではありません。足・トゥ・TPUのうち最も低い部分が接地するため、実際の支持高さは姿勢と形状から調べます。`check_urdf.py` は4脚のTPU先行接地と同一平面性も検査し、不適合をNGとして返します。

2026-09-05 の `gait.h` 停止保持では `STANCE_OFF_XY` を含み、SWAYを止めます。高さ115mmの目標角は以下です。これはPWM量子化前の角度です。

| 脚 | yaw | pitch | knee |
|---|---:|---:|---:|
| FR | +5.410929° | −32.826007° | +21.507285° |
| FL | −5.410929° | −32.826007° | +21.507285° |
| RL | +8.488133° | −25.741822° | +4.519793° |
| RR | −8.488133° | −25.741822° | +4.519793° |

腕のREADY目標は両側 yaw=10°、pitch=30°、elbow=40°です。脚の姿勢に応じて腕のガードが働きます。通常起動は脱力状態で、明示的な起動後に20軸を順番に通電します。通電直後の脚中立0°、腕0°/0°/45°と停止保持姿勢は異なります。保持姿勢から始めた物理計算は、この起動過程を検証したことにはなりません。

URDF角度は、機構側の角度を度からradへ換算したものです。脚の取付方位は `joint origin` に含め、左右腕の鏡像は原点・軸で処理します。URDF関節値へ追加の符号反転をしないでください。実PWMには `JOINT_SIGN`、`ARM_SIGN`、トリム、4.88µs刻みの量子化が別途作用します。`sim_stress.py` の標準設定は、実C++の Gait/LegOutput/Arms/Servos をホスト実行し、量子化後の指令を使います。

## 関節とPWMの対応

| URDF関節 | PCA9685 | グローバルch |
|---|---|---|
| leg_fr_yaw / pitch / knee | 0x40 | 0 / 1 / 2 |
| leg_fl_yaw / pitch / knee | 0x40 | 3 / 4 / 5 |
| leg_rl_yaw / pitch / knee | 0x40 | 6 / 7 / 8 |
| leg_rr_yaw / pitch / knee | 0x40 | 9 / 10 / 11 |
| arm_r_yaw / pitch / elbow | 0x41 | 16 / 17 / 18 |
| arm_l_yaw / pitch / elbow | 0x41 | 20 / 21 / 22 |
| eye_r_roll / eye_l_roll | 0x41 | 24 / 26 |

ch12の `CH_HEAD` は駆動対象未確定のため使いません。URDFの関節にも質量調整用の9gにも含めません。ch19/23は予約、中央目ch25は固定カメラなので非駆動です。固定カメラは `eye_pod_camera_fixed` → `camera_optical_fixed` の2固定関節で表し、`camera_optical_frame` の+Zを光軸に合わせます。

## 形状と質量

脚の各リンクには骨格とその部位の外装を付けます。`tibia` には足本体・脛外装・3本のトゥ・**TPU foot_pad の表示と質量**を含めます。腕の指先は固定で、別の可動自由度はありません。組立手順で不採用の `Head_Plate_Grey` と `Head_Bottom_Cap_Grey` は現在の組立から除外します。元モデルは保存します。

トゥの組立行列だけ100%だった不整合は、印刷指定と同じ150%へ修正しました。根元点を固定して拡大するため、従来の小さいトゥを使った接地・質量結果は現行版の根拠にできません。砲身・ボール・ネックは加工済み `_Bored` を元原型の基準座標で取り込みます。

印刷質量は表面積×壁厚と内部充填率からの見積りです。慣性と重心は均質メッシュの値を見積質量へ比例換算するため、実印刷の壁、充填、接着剤、ネジ、配線による重心差は未実測です。STLから算出できたことと実重量が確認済みであることを区別します。

サーボ質量は DS3218=60g、MG90S=14g、目の小型サーボ=3.7g の設計値です。主ケースの取付座標をCADと共有し、タブ下面を原点、ケース側を `−TAB_BELOW`、軸側を `+ABOVE_TAB` とする箱近似で重心と慣性の回転を計算します。軸が下向きならケースが上へ伸びます。目サーボはポッド背面からホーン積層6.1mmを引いたタブ位置に固定し、目と一緒には回転させません。接着時の固定ロールは未確定です。

バッテリー・制御基板・電源・音声系の質量と配置には概算が残ります。電装のシャーシ基準座標には `HIP_DROP` を加えてURDF基準へ変換します。収納候補を変更した場合は、この質量配置も同期する必要があります。`camera_optical_frame` の微小な質量も物理実測値ではなく取り込み上の仮定です。合計質量の現在値は生成ログと `check_urdf.py` の結果を参照し、過去の約2.78kgを固定値として使わないでください。

## トルク・速度の前提

メーカー端点は `config.py` の `POWER_COMPONENTS`、運用電圧は `POWER_AUDIT['servo_v']` に集約します。URDF既定は6Vの直線内挿です。

- DS3218: 5Vで18kgf·cm / 0.16秒/60°、6.8Vで21.5kgf·cm / 0.14秒/60°。6V内挿は約1.956N·m、7.034rad/s。[メーカー資料](https://www.dsservo.com/down.asp?id=22)
- MG90S: トルク4.8Vで1.8kgf·cm、6.6Vで2.2kgf·cm。速度4.8Vで0.10秒/60°、6Vで0.08秒/60°。6V内挿は約0.203N·m、13.090rad/s。ただし同じページのOperating Voltage欄は4.8Vであり、購入個体の6V適合をこの表だけで確定できません。[TowerPro仕様](https://towerpro.com.tw/product/mg90s-3/)
- 目の小型サーボ: 0.03N·m、8rad/sは未実測の仮定です。

これらは停止時最大トルクと無負荷速度の目安で、両方を同時に出せるという意味ではありません。MuJoCo側は速度に応じて駆動方向のトルク余裕を下げる直線近似を使います。実サーボの制御特性、摩擦、発熱、連続トルク、電源降下は未同定です。URDFの `<limit>` だけでは、このトルクと速度の関係や50Hz更新・スルーレート・ガードを再現できません。

## 衝突の扱い

URDFの従来型衝突形状は、可動リンク単位の凸包と、ベースのシャーシ・頭・ポッド・砲身に分けた凸包です。面数を減らした凸包は穴や空隙を埋め、元形状を厳密に外包する保証もありません。外装どうしの偽接触と本当の部品交差の両方があり得ます。

第2次監査では `sim_collision.py` が元部品ごとに材料を分け、単一凸包とVHACD凸分解を比較します。20個のサーボ主ケース、目の保持板も追加でき、TPUと硬い外装の床反力を別々に記録します。主ケース以外のタブ、ホーン、配線全体を含む完全な接触モデルではありません。TPUの設定は接触の柔らかさを近似するもので、ゴムの有限要素解析ではありません。

自己衝突を有効にする際は、隣接リンクの接触フィルタも区別します。`sim_self_collision.py` は重なる全リンクのAABBとMuJoCo接触から候補を列挙し、元部品の実メッシュをBoolean交差して追試します。初期貫通を衝突除外で消して合格にしません。固定リンク内の部品どうしは別途機構監査が必要です。実際の停止保持でも交差が見つかっているため、「firmwareが到達できる姿勢なら干渉しない」という旧説明は成立しません。[MuJoCo接触計算](https://mujoco.readthedocs.io/en/stable/computation/index.html#contact)

## 実行と判定

```sh
.venv/bin/python tools/tests/simulation_regression.py
.venv/bin/python tools/sim_self_collision.py --include-servos --out /tmp/tachikoma-self.json
.venv/bin/python tools/sim_stress.py --cases docs/audits/20260905-round2/simulation/stress-cases.json --out /tmp/tachikoma-stress
```

`check_urdf.py` は構造・可動軸・変換・部品対応・メッシュ書出し・慣性の正定値性・実支持などを検査し、NGなら終了コード1を返します。件数はコードと生成物により変わるため末尾を参照します。

物理試験は各条件のJSONに入力SHA-256、エンジン版、指令列、転倒、数値警告、飽和、材料別荷重、軸出力を保存します。`NUMERICAL_FAILURE` は数値計算の破綻、`INVALID_INITIAL_CONTACT_MODEL` は初期貫通、`FALL` は姿勢条件での転倒です。条件付きの `PASS` でも実機準備完了を意味せず、`physical_readiness` は未確認です。正の機械仕事率だけから電源電流を決められません。静止保持電流や損失は別に測定します。

## Isaac Sim で使う場合

**今回、Isaac Simでは実行していません。** 特定の版のUI・既定値・取り込み挙動は確認していません。フォルダ構成を保って取り込み、以下を使用環境で確認してください。

1. 脚で接地する自由ベースとして取り込み、20可動関節と2固定関節の対応を確認する。
2. `camera_optical_frame` をカメラに使う場合、固定関節の統合で消えていないか確認する。
3. 位置制御ゲイン、50Hz出力、角度符号、スルーレート、関節ガード、速度依存トルク限界を別途実装する。URDFには能動制御ゲインも受動摩擦の実測値も含まれない。
4. 自己衝突有効時の初期接触を点検する。現在の実干渉を無効化して物理成立と判定しない。

## 旧配布物と出自

`tachikoma_urdf_20260731/` と `tachikoma_urdf_20260822.zip` は過去版として保存しています。第2次監査で全ファイルのハッシュ、STL、XML、同梱文書・比較画像を確認しました。現在の慣性、TPU、トゥ倍率、加工済み砲身、Cabin位置、非採用部品の修正は過去版へ自動反映されません。旧版を現在の製作根拠に使わないでください。

新しい配布物を作る場合は新しい日付のファイル名と入力ハッシュ一覧を使い、生成・検証結果と組み合わせます。更新時刻だけでは内容一致を確認できません。今回、過去版を上書きしていません。

元キットはプロジェクトオーナー自身の著作物です。骨格と保持部品は `hardware/src/*.py` の設計です。元STL、組立変換、派生形状、過去の証拠を区別して保存します。

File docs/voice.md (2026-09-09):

# 音声会話ユニット — アーキテクチャと運用手順

タチコマの砲身 (Mouth_Cannon) にマイクとスピーカーを内蔵し、STT (音声認識) →
LLM (対話) → TTS (音声合成) を経由して会話する。**運用は PTT (Web UI の
ボタンを押している間だけ録音) の半二重** — 再生中は録音しない。
音声処理そのもの (STT/LLM/TTS) は ESP32 では行わず、Mac 等で動く
`tools/voice_bridge.py` (ブリッジ) が Wi-Fi 経由で仲介する。

## 全体アーキテクチャ

```
┌─────────────┐  Wi-Fi (iPhone インターネット共有 or 自宅LAN)  ┌────────────────────┐
│   ESP32     │◀──────────────────────────────────────────▶│  ブリッジ (Mac等)  │
│  (タチコマ) │   ws://tachikoma.local/audio                │  tools/voice_bridge │
│             │   バイナリ=PCM 16kHz/16bit/mono             │  .py                │
│ INMP441 マイク│   テキスト=JSON制御                          │                    │
│ MAX98357A   │   {"type":"ptt_start"|"ptt_end"             │  STT → LLM → TTS   │
│  アンプ+砲身 │        |"tts_begin"|"tts_end"}              │  の順に外部API呼出  │
│  内スピーカー │                                              └─────────┬──────────┘
└─────────────┘                                                        │
                                                          ┌──────────────┼──────────────┐
                                                          ▼              ▼              ▼
                                                   OpenAI whisper-1  Anthropic API  ElevenLabs
                                                   (STT)             (claude-sonnet-5) (TTS, 声クローン)
```

- **ESP32 が WebSocket サーバ** (`/audio`)、**ブリッジがクライアント**として
  接続しにいく (操作系の `/ws` とは別エンドポイント。両方 ESP32 側がサーバ)
- 音声フォーマットは全経路で **PCM 16kHz / 16bit / mono** (リトルエンディアン)
  に統一。ESP32内のI2S DMAは32bitで、音声サンプルと明示的に変換する。STT 送信時のみブリッジ側で WAV コンテナに包む (whisper API の要件)
- **半二重運用**: 再生中 (`tts_begin`から受信済み音声の再生終了まで) は ESP32 側が録音を止める
  (firmware `Audio` クラス。マイクがスピーカー音を拾うエコーの回避。AEC 無し)
- I2S ピン割当・電源配線は `docs/wiring.md` の「音声ユニット (I2S) 配線」参照
- 会話の押し込み口 (PTT) は既存 Web UI (`/ws`) 側のボタンから
  `Audio::setPtt()` を叩く前提 (firmware 側の実装。本ドキュメントの担当外)

## 1. iPhone インターネット共有への接続 (STA 設定)

ESP32 は `WIFI_AP_STA` で起動する。操作 UI の AP は、書き込み前に
`firmware/src/config.h` の `AP_PASS` を自分だけが知る 8〜63 文字の値へ変更した
場合にだけ有効になる。リポジトリに置かれた値はプレースホルダー
`change-me-8chars` なので、そのままでは AP を起動せず、`ap_ready=false`・状態
`AP_UNCONFIGURED` となる。実運用値をリポジトリへコミットしないこと。

最初の書き込みでは、まずローカルの `config.h` だけを編集して再ビルド・書き込み
を行い、その後に AP `Tachikoma` (`http://192.168.4.1/`) へ接続する。AP を有効に
できない状態ではこのアドレスは使えないため、設定済みの STA またはシリアル等の
別経路を先に用意する。ブリッジがインターネット (OpenAI/Anthropic/ElevenLabs)
へ届く経路として、ESP32 を iPhone のインターネット共有 (テザリング) へ
**STA として追加接続**させる。

1. iPhone の「設定」→「インターネット共有」を ON にする (Wi-Fi パスワードを
   確認しておく)。**iPhone 12 以降は「互換性を最大にする (Maximize
   Compatibility)」を必ず ON** にする — OFF (既定) だとテザリングが 5GHz 帯
   になり、**2.4GHz 専用の ESP32-WROOM からは SSID が見えず接続できない**
   (Web UI 上は「未接続」のままで原因表示は出ない)。ON にすると 2.4GHz 化
   され接続できる (確認日 2026-07-28, Apple 公式のインターネット共有設定
   項目)
2. `AP_PASS` を変更して書き込んだ場合だけ、スマホ/PC で ESP32 の AP `Tachikoma`
   (パスワード = 自分で設定した `AP_PASS`) に接続し、`http://192.168.4.1/` を開く。
   プレースホルダーのまま書き込んだ場合、この AP 手順は利用できない
3. Web UI の Wi-Fi 設定欄 (SSID / パスワード入力欄) に iPhone のテザリング
   SSID とパスワードを入力して保存する (`POST /wifi`, フォームパラメータ
   `ssid` / `pass`。ESP32 側で NVS に保存し即座に `WiFi.begin()` する)
4. 接続状態は `GET /wifi` が `{"ssid":..., "connected":true, "ip":"..."}` を
   返せば確認できる (`curl http://192.168.4.1/wifi`)
5. Mac 側も同じ iPhone テザリングの Wi-Fi へ接続する (ブリッジと ESP32 が
   同じネットワークに居る必要がある)
6. `ping tachikoma.local` (または `http://tachikoma.local/`) で到達確認
   (mDNS ホスト名は `tachikoma`, firmware `MDNS_HOST` 参照)。mDNS が届かない
   環境 (一部 iPhone テザリング条件) では `GET /wifi` で得た IP を
   `voice_bridge.py --host <IP>` に直接渡す

## 2. ブリッジの起動

Mac 上 (iPhone テザリングの Wi-Fi に接続した状態) で実行する。常時稼働
させたい場合はクラウド VM 上でも動かせるが、その場合は VM 側から ESP32 の
`/audio` へ到達できるネットワーク経路 (VPN 等) を別途用意すること
(タチコマが自宅外に出ない前提なら Mac 常時起動の方が単純)。

```bash
# 環境変数を用意 (シェルの rc ファイルや direnv 等。ハードコード禁止)
export OPENAI_API_KEY=...
export ANTHROPIC_API_KEY=...
export ELEVENLABS_API_KEY=...
export ELEVENLABS_VOICE_ID=...

# 実運用 (既定で ws://tachikoma.local/audio へ接続)
.venv/bin/python tools/voice_bridge.py

# mDNS が使えない場合は IP を直接指定
.venv/bin/python tools/voice_bridge.py --host 192.168.x.x

# オフライン疎通試験 (API 呼び出し無し。ダミー WS サーバ相手に
# ptt_start→PCM→ptt_end→tts_begin→PCM(440Hzトーン)→tts_end の
# 一往復を検証して終了する)
.venv/bin/python tools/voice_bridge.py --mock --self-test
```

- 接続が切れても自動的に再接続を試みる (指数バックオフ, 最大 30 秒間隔)
- LLM のペルソナ (口調・性格) は `tools/voice_persona.md` を直接編集する
  (system プロンプトとしてそのまま読み込まれる)
- 会話履歴は直近 `--history-turns` ターン分 (既定 6) だけ保持し、それより
  古いやり取りは LLM への入力から自動的に落ちる
- `--anthropic-model` / `--openai-model` / `--elevenlabs-model` で使用モデル
  を上書きできる (既定はそれぞれ `claude-sonnet-5` / `whisper-1` /
  `eleven_multilingual_v2`)

## 3. ElevenLabs でのボイスクローン作成 (概略)

1. ElevenLabs のアカウントを作成し、Voice Lab (Voices → Add Voice →
   Instant/Professional Voice Cloning) を開く
2. 声のソース音源 (下記「権利上の注意」を遵守したもの) を数十秒〜数分分
   アップロードしてクローンを作成する
3. 作成した Voice の詳細ページに表示される `voice_id` を控え、環境変数
   `ELEVENLABS_VOICE_ID` に設定する
4. API キーは ElevenLabs のアカウント設定から発行し、
   `ELEVENLABS_API_KEY` に設定する
5. `tools/voice_bridge.py` は `output_format=pcm_16000` でストリーミング
   合成を要求する (追加のデコード処理なしで ESP32 の I2S へそのまま渡せる
   フォーマット)

## 4. 遅延の目安

UNVERIFIED (実測前の見積り。iPhone テザリング + 各社 API のレスポンス次第で
変動する):

| 区間 | 目安 |
|---|---|
| 発話終了 (`ptt_end`) → STT 結果 | 0.5〜1.5 秒 |
| STT 結果 → LLM 応答テキスト | 0.5〜2 秒 (応答の長さ・持ち越し履歴に依存) |
| LLM 応答 → TTS 最初の音声チャンク | 0.3〜1 秒 (ストリーミングのため以降は継続的に届く) |
| **体感の合計 (無言〜再生開始)** | **概ね 1.5〜4 秒** |

ペルソナ側で返答を短く (1〜3 文) に制限しているのは、LLM/TTS の生成時間を
抑えて体感遅延を減らす狙いも兼ねている。

## 5. カメラ連携 (任意, 2026-07-28 頭部中央目へ移設)

**2026-07-28 設計変更**: カメラはポッドのメインアイではなく**頭部の中央
可動目を固定カメラ目に置換したもの** (`eye_pod_camera` + `camera_carrier`,
瞳径φ10mm) に内蔵する — 左右 2 目はキョロキョロのまま。撤去理由: ポッド
前面の位置は前方視界の約 80% が自機体に遮蔽されることが実測で判明した
ため (`tools/check_camera.py` [4] が恒久チェックする)。本体制御とは独立した
WiFi カメラモジュール (推奨: Seeed XIAO ESP32S3 Sense。BOM #34 参照) を
使う点は変更なし。**メインの ESP32-WROOM (脚/腕/頭部/音声を制御) は動画
を一切扱わない** — カメラモジュールは自前で iPhone インターネット共有へ
接続し、標準的な ESP32 カメラ用ファームウェア (Seeed/Espressif の
CameraWebServer サンプル等, 本リポジトリの `firmware/` 外) で MJPEG
ストリーム/静止画キャプチャの HTTP サーバを立てる。ハードウェア設計
(光軸の偏心角・瞳開口・内蔵キャリアの寸法根拠) は `hardware/src/make_camera.py`
と `hardware/src/config.py` の `CAM2_*` コメント、検証は
`tools/check_camera.py` 参照。

```
┌──────────────┐  Wi-Fi (iPhone インターネット共有, 音声ユニットと共用)
│ カメラモジュール│◀───────────────────────────────────▶  ブリッジ (Mac等)
│ (XIAO ESP32S3 │   http://<camera-ip>/capture               tools/voice_bridge
│  Sense, 独立)  │   (静止画 JPEG/PNG を1枚返す HTTP GET)      .py --camera-url
└──────────────┘                                              │
                                                                ▼
                                                          Anthropic API
                                                          (画像コンテンツ
                                                           ブロックとして送信)
```

- `tools/voice_bridge.py --camera-url http://<camera-ip>/capture` を付けて
  起動すると、**発話 (ptt_end) を処理するたびに** このURLへ HTTP GET で
  静止画を1枚取得し、LLM (Anthropic API) へ画像コンテンツブロックとして
  渡す。MJPEGの場合は最初のJPEGで接続を閉じ、4MiBの上限と取得期限を設ける。画像は毎ターンの「今の一枚」のみを送り、会話履歴には残さない
  (`fetch_camera_image_block`/`llm_respond` 実装参照)
- 取得に失敗した場合 (カメラ未起動/URL誤り/タイムアウト等) は警告ログを
  出して**画像なしで音声パイプラインを継続する** — カメラの不調で音声会話
  全体が止まることはない
- `--camera-url` を省略した場合は従来通り画像なしで動作する
  (`--mock --self-test` の自己試験もこの既定動作のまま変わらない)
- カメラモジュール自体の WiFi 接続設定・ストリームサーバ起動は、選定した
  ファームウェア (CameraWebServer 等) 側の設定次第 (本ドキュメントの担当
  範囲外)。iPhone インターネット共有への接続手順は §1 と共通
- **プライバシー注意**: カメラ映像/静止画は録画・保存する用途を意図せず、
  発話のたびに1枚取得して LLM へ渡すだけの設計 — 常時録画・外部公開する
  構成に変更する場合は、写り込む人物・場所への配慮を別途検討すること

## 6. 権利上の注意 (重要)

- **タチコマ (攻殻機動隊) の声優本人の声のクローンは私的利用の範囲に
  留めること。** 生成音声・ボイスクローンモデルの公開・配布・商用利用は
  しない
- 音声データ (クローン学習用のソース音源) はユーザー自身が適法に用意した
  ものを使う。本リポジトリには音声データ・クローンモデル・API キーの
  いずれも含めない
- `tools/voice_persona.md` (口調テンプレート) 自体もキャラクター設定を
  含むため、公開・配布する場合は同様の注意が必要

## トラブルシューティング

- `voice_bridge.py` が「環境変数が未設定です」で終了する: 4 つの API キー
  環境変数 (`OPENAI_API_KEY` / `ANTHROPIC_API_KEY` / `ELEVENLABS_API_KEY` /
  `ELEVENLABS_VOICE_ID`) を確認する。オフライン確認だけなら `--mock` を使う
- ESP32 に接続できない: iPhone テザリングに Mac も接続しているか、
  `GET /wifi` で `connected:true` か、`tachikoma.local` の代わりに IP
  直指定で届くかを確認する
- 音声が途切れる/エコーする: `docs/wiring.md` の I2S 配線 (特に GND) を
  再確認する。エコーが出る場合は再生音量を下げる (AEC 非搭載のため、
  半二重運用の前提が崩れると回り込みが起きる)
- 応答の途中 (特に長めの返答) で音声がぶつ切りになる/後半が無音になる:
  配線よりも先に、ブリッジの TTS 送信ペーシングとファームウェア側の
  再生リングバッファ溢れを疑う。ESP32 の再生リングバッファは約 0.5 秒分
  しかなく、溢れるとサンプル単位で切り捨て、シリアルとWebSocketのoverflow通知を出す。`voice_bridge.py` は
  ElevenLabs から届いた PCM を実時間の再生速度 (16kHz/16bit/mono =
  32000 bytes/秒) に合わせてペーシング送信するようになっているので、
  この症状が出る場合はまず `voice_bridge.py` が最新か (ペーシング処理が
  入っているか) を確認する
- `--camera-url` を指定しても LLM の応答が画像を見ていない様子: ログに
  `[camera] 静止画取得 ...` が出ているか確認する (出ていなければ URL 誤り/
  カメラ未起動/タイムアウトで取得失敗しており、ログに
  `カメラ画像の取得に失敗しました` と例外が出ているはず)。取得できていても
  応答に反映されない場合は `--anthropic-model` が画像入力対応モデルか確認
  する

## 2026-09-05の検証範囲

実コードのホスト試験、ローカルWebSocket、疑似HTTP応答で録音・再生・取消・部分書込を検証した。
本番API・実マイク・スピーカー・カメラの往復は未実施。結果は[第2次制御監査](audits/20260905-round2/firmware.md)。
既定の`claude-sonnet-5`は[Anthropicのモデル一覧](https://platform.claude.com/docs/en/models/overview)で
2026-09-05に存在を確認したが、使用アカウントでの利用可否は未確認。

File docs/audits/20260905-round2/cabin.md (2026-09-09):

# Cabin 電装室・背面蓋の再設計候補（2026-09-05）

現行の殻は内部まで中実であり、そのままでは基板を収容できない。前殻に後方からアクセスする左右2段の収納室を設け、各棚を M3×10 タッピング2本で固定する候補を作成した。背面蓋は既存ペグ穴を使う交換ペグの板ばねで保持し、後方へ引いて取り外す。外側の新穴と磁石は不要。**収納室・棚・ラッチの69項目は合格だが、Cabin Eye、首、Ballなどとの全組立には実体交差が残る。全体の組立合格ではない。現物寸法・熱・保持力の確認も残り、候補は標準生成・印刷対象へ自動適用していない。**

## 確定した既存欠陥と修正

- `Cabin_Front_Blue.stl` は 1,956,201 mm³、`Cabin_Back_Blue_Repaired.stl` は 679,935 mm³の中実。基板を収める空洞・固定座・配線経路が設計されていなかった。
- 後殻の従来高さ Z=55 mm では2本の元ペグ穴が前殻に対して6.3075 mmずれていた。後殻Z=48.692503 mmに合わせると、元ペグ2本の殻との交差は0になる。前の配置では同じ2本が計3,727.19 mm³交差した。`config.CABIN_POSES`、`config.CABIN_PEG_POSES`、`kit_assembly`、装飾6個への位置反映は主担当が統合済み。
- Boolean内部で閉じた形状でも、書き出したSTLを読み戻すと元殻の極小稜線が重なり4面接続になる現象を捕捉。候補の最終書き出しは0.015 mm以内の簡略化を行い、**再読後の閉体・単一体**を改めて確認する。外観寸法の基準0.1 mmより小さい修復であり、既存STLは上書きしない。

## 候補の構成

全成果物は `cabin-electronics/`。全て**シャーシ底面Z=0の組立座標**で、さらに姿勢補正を重ねない。寸法の定義は `tools/design_cabin_electronics.py`、ラッチは `tools/design_cabin_latch_candidate.py` に集約した候補値である。製造対象に採用する際は `hardware/src/config.py` へ移す。

| 部品 | 候補STL | 数量 | 役割 |
|---|---|---:|---|
| 前殻 | `candidate_cabin_front_with_wire_route.stl` | 1 | 収納室、棚固定座、φ8配線路 |
| 後殻 | `candidate_cabin_back_with_latches.stl` | 1 | 左右渡り配線室、ラッチ受け |
| 左右棚 | `candidate_carrier_0.stl` / `candidate_carrier_1.stl` | 各1 | 基板の絶縁保持・ベルト穴・USB開口 |
| 交換ペグ | `candidate_latch_peg_lower.stl` / `candidate_latch_peg_upper.stl` | 各1 | 前殻側は元形状、後殻側に各2本の板ばね |
| 比較用 | `candidate_cabin_front_pockets.stl`、`candidate_cabin_back_crossover.stl`、`candidate_peg_*.stl` | — | 配線口やラッチを追加する前の比較形状 |
| 検査用 | `candidate_latch_peg_*_deflected.stl`、`candidate_wire_route.stl` | — | 変形・通線包絡。印刷部品ではない |

左右棚中心X=±32 mm。下段収納室は幅36×奥行71×高さ38 mm、上段は幅35×奥行59×高さ31 mmで、背面開口付近を追加で逃がす。棚板厚2.4 mm、壁厚1.5 mm。2本ずつの後方から入れるM3×10は、棚3 mm＋棚と座の間1 mmを越え、固定座へ6 mmねじ込む。下穴は共通定数 `C.M3_TAP`、通し穴は `C.M3_FREE` を使用。皿頭のねじでは面圧が変わるため、実購入ねじの頭部と下穴適合は試験する。

基板は裸の銅面を棚へ接触させず、既存の絶縁材・ベルトで固定する。棚の穴は幅2.6×長さ6 mmで、3 mm超の結束バンドは入らない。ベルト・フォームの厚みは下の予約体積内に含めること。接着だけでの基板固定を前提にしない。

| 基板・配線の予約体 | 予約寸法 X×Y×Z [mm] | 判断 |
|---|---:|---|
| ESP32本体＋縦ヘッダ | 30×58×28 | PCB 58×28を収める予約。実端子・USB位置は未確認 |
| UBEC | 30×59×28 | HOBBYWING 45×20×16.2 mm本体を含む。購入記録のHENGE 8Aの適合は未確認 |
| DFPlayer | 26×26×20 | 実ピン・microSD・プラグ要実測 |
| MAX98357A | 24×22×20 | 基板と端子の予約。実モジュール種類要実測 |
| 5V変換基板 | 28×38×20 | mini560の種類、調整部・放熱要実測 |
| USBプラグ | 14×29×12 | 後殻を外すと挿入空間を確保。後殻を閉じたままでは交差する |

HOBBYWINGの寸法は[メーカー掲載のUBEC-10A-V2](https://www.hobbywing.com/products/ubec-10a-car79)を参照。購入履歴のHENGE 8Aと型番が異なるため、これだけで所有品の適合は認定しない。XIAOは短いカメラFPCの制約から頭側へ配置する方針であり、Cabin内の予約体に含めない。

## 通線と保守

左右の配線は後殻内側の幅74×奥行12×高さ12 mmの渡り空間を通り、前殻のφ8経路へ合流する。経路は曲げ半径25 mmで、ネック接合面のX=0、Z=10 mmへ出る。元ペグ周囲を避け、棚と全基板予約体に交差しない。前殻のφ8出口は既存ネックに隠れる接合面であり、外側の見える面への穴は追加していない。

ネック側のφ8孔と出口候補は `neck-wire-candidates/` に別途作成されており、根元補強と併せて主担当・機構担当が確認する。旧ネック40%印刷近似の安全率2.72は要求3未達だったため、**通線孔だけを旧ネックへ追加して製造してはいけない**。線束径、コネクタの通過、屈曲半径、蓋を抜くための余長、熱上昇は未確認。USB接続時は後殻を取り外し、電源の接続順は改訂した配線手順に従う。

## 背面蓋の保持

交換ペグ2本は前半形状を元ペグと一致させ、**Front側にだけ接着**する。Back側と板ばねには接着剤を付けない。各ペグ後半の板ばね2本が0.6 mm噛み合う。挿入側30°、抜去側60°の斜面で、蓋をまっすぐ引くと板ばねが押し下がって外れる。外側の解除穴や別部品は不要。蓋の装飾を引っ張らず、殻本体を持って操作する。

- 有効梁長15 mm、幅7 mm、厚さ1.6 mm。無荷重で嵌合し、閉じたまま変形を保持しない構成。
- 蓋を0.25 mmずつ動かす実メッシュ検査では、必要な自由端変形は下ペグ最大0.651 mm、上ペグ最大0.697 mm。0.85 mm押下形状に対して蓋を20 mm連続移動する全包絡の交差は0。
- 片持ち梁の式 `ε=3tδ/(2L²)` では最大ひずみ約0.744%。これは切り欠きの応力集中や積層方向を含まない。
- 印刷PETGの弾性係数を **800～2000 MPaの仮定範囲**で振ると、4本が同時に効く理想状態で挿入力2.74～6.84 N、抜去力8.21～20.52 N。摩擦・寸法誤差・実材料係数は含まず、実測した保持力ではない。

試験はペグ単品と対応するソケットを先に印刷する。層が梁根元で剥がれる向きを避け、梁長方向へ連続する造形線と十分な外周を選ぶ。最終向きはサポート痕を含めて試験片で決める。目安として、無荷重で蓋が閉じ、開閉50回後にも白化・割れ・塑性変形がなく、実測した蓋重量と歩行時加速度から必要保持力を決定する。仮の確認条件は静的5 Nで外れず、20 N程度以下で手で解除できること。後者は快適な操作の仮目標であり、歩行保持の合否は実質量・加速度から決める。機体落下や転倒をこのラッチだけで防ぐ設計ではない。

## 再現と判定

```sh
.venv/bin/python tools/design_cabin_electronics.py
.venv/bin/python tools/design_cabin_latch_candidate.py
.venv/bin/python tools/check_cabin_candidate.py
.venv/bin/python tools/render_cabin_candidate.py
```

`candidate-report.json` は収納室と通線、`latch-report.json` は変形経路と梁の感度計算、`independent-check.json` は書き出したSTLを読み直した69項目の検査（全項目合格）と最終ハッシュを持つ。`candidate-parts.json` に6部品の体積・座標変換・候補パラメータ・製造前の未確認条件をまとめた。図は `candidate-overview.png`、組立閲覧用は `candidate-assembly.glb`。元キット姿勢の根拠は `tools/data/cabin_peg_alignment_candidate.json`。

| 項目 | CAD検査 | 実物の判断 |
|---|---|---|
| 殻・棚・交換ペグの閉体、単一体 | 最終STL再読で確認 | 印刷結果は未確認 |
| 元殻外形 | 0.015 mm簡略化、0.03 mm各軸膨張内を独立検査 | 元STLは未変更 |
| 外壁 | 接合面以外は3.3 mmの膨張で事前検査。簡略化を考慮して3.2 mm以上 | 実壁・印刷欠陥は未確認 |
| 棚・基板の挿入 | 後方70 mmの連続包絡で交差0 | コネクタと配線を付けた状態は未確認 |
| 閉じた蓋・交換ペグ | 殻・棚との交差0 | 接着と保持力は未確認 |
| ラッチの抜去 | 最大押下形状で20 mm連続経路が交差0 | 力・疲労・摩耗は未確認 |
| 基板予約体 | 殻・棚・配線との交差0 | 購入品の寸法が予約内か未確認 |
| ネック通線 | φ8・R25の候補経路 | 補強、線束、実負荷確認待ち |

## XIAO公式STEPの追加計測

機構担当が取得した2023年のSeeed公式STEPをOCCTで読み、組立の変換を適用して全部品の境界を計測した。単純な21×17.8 mmの箱はUSBの張り出しと拡張基板を含まず、カメラを取り外した予約寸法は **microSDなし22.782×17.780×8.030 mm、あり24.363×17.780×8.500 mm**。FPCコネクタ中心・寸法・右手系の平置き変換を `primary-sources/xiao-step-measured/camera-removed-summary.json` に保存した。

再現用は `tools/measure_xiao_step.py`。OCP/VTKは `/tmp/tachikoma-step-runtime` へ隔離して導入し、既存`.venv`を変更していない。`PYTHONPATH=/tmp/tachikoma-step-runtime .venv/bin/python tools/measure_xiao_step.py` で再計測できる。細部のSTEPには開いた面が含まれるため、部品STLは閲覧用であり、干渉検査は閉体の予約箱を使う。旧カメラ世代のモデルで、交換OV3660のFPC長・実購入基板の種類を認定するものではない。

## 追加の全組立確認：不合格

収納室を作った前殻を既存の意匠部品と比較する追加検査を行った。これは上記69項目に含まれていなかった関係であり、局所検査の合格を全組立の合格として扱わない。`cabin-electronics/external-interface-check.json` に元の前殻と候補の比較を保存した。

| 前殻との相手部品 | 元の交差 [mm³] | 候補で残る交差 [mm³] | 判定 |
|---|---:|---:|---|
| 既存pod_neck | 1199.55 | 1034.57 | 未解消 |
| Cabin_Eye_White | 7784.87 | 7548.03 | 未解消 |
| TailJoint Blue | 0.404 | 0.404 | 接触・配置要精査 |
| TailJoint Ball | 1152.80 | 829.91 | 未解消 |

収納室の空洞化ではCabin Eyeの食い込みを解消できない。元のrear JSON自身が「Eyeの境界箱中心を取付リング面へ置いたため、接着縁が約7.4 mm内側へ入る」と記録しており、取付基準面を合わせる修正が必要である。法線方向の0～15 mmの位置候補は `tools/probe_cabin_eye_alignment.py` で別途切り分け、標準位置は変更しない。元画像と接着縁の正確な基準が不足するため、非交差だけで正しい接合と判断しない。

首本体とBlue/ Ballの交差も意図した嵌合ではない。Blueの頭側先端とBallの円板は中実なのに、旧neck梁は全長にわたって貫通する。頭の局所逃げと強度だけを改善した候補は `neck-reinforcement-candidates/comparison.json` にあるが、全候補で全組立を不合格と明記した。Cabin内部、首の支持経路、意匠部品の基準面を一体として再設計する必要がある。

### Eye位置の有限比較結果

法線方向0～15 mmを0.5 mm刻み、さらに7.39 mmを測定した。Eyeの実メッシュの法線方向半厚みは7.3935 mmで記録と一致するが、7.39 mm押し出しても元Frontとの交差3296.55 mm³、収納室候補との交差3106.10 mm³が残る。neckとの交差は878.34から2054.83 mm³へ増加する。Frontとの交差が消える最初の格子点は13.0 mmだが、**首・Blue・Ballを含む全非交差姿勢は試した範囲にない**。半厚みを足すだけでは修正できないことを反証した。

`eye-position-probe.json` は全32姿勢、`candidate_cabin_eye_half_depth7p39.stl` は比較用の可視位置候補であり、正しい装着位置を確定したものではない。

## 最新の本流との再照合

最終のconfig/KIT/libに対して電装室・ラッチを再生成し、独立71項目が合格（既存69項目にlib.pyの入力ハッシュ一致2件を追加）。外部組立は引き続き失敗で、候補Frontと首約1034.567mm³、CabinEye約7548.030mm³、Ball約829.906mm³の交差が残る。`cabin-electronics/latest-*.log`と`independent-check.json`/`external-interface-check.json`を参照。候補は本流未採用。

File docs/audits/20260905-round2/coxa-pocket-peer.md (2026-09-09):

# 股ピッチ用サーボ穴の再貫通に対する独立評価

天板の合成でサーボ穴を埋め戻していた不具合に対し、全形状合成後に `servo_pocket` と `servo_tab_holes` を再減算する修正を確認した。元の外形を増やさず、サーボと共有していた空間を除く幾何修正として妥当。印刷強度の合格は主張しない。

候補STLは単一の閉体、18,729.996mm³。サーボ負形状との残交差0.000228mm³、ホーン負形状0.000007mm³、タブビス穴0.000016mm³。上板の基準下面はcase半幅+公差=10.3mmで、その上にある直接支持板の旧新差集合は0.000100mm³。ホーン腕溝の下には3.600mmの床があり、pilot x14.4/19.84mmの各穴の周囲4半径×16方位でも同じ厚さだった。

| 上向き力 F (N) | pitch反力偶力 (N·m) | 上板中実の安全率近似 | 壁1.6mm/40%の安全率近似 |
|---:|---:|---:|---:|
| 22.370 | 1.770 | 2.403 | 2.295 |
| 22.370 | 1.956 | 2.227 | 2.126 |
| 37.278 | 1.770 | 2.063 | 1.970 |
| 37.278 | 1.956 | 1.932 | 1.845 |
| 44.730 | 1.770 | 1.927 | 1.840 |
| 44.730 | 1.956 | 1.812 | 1.730 |

すべての荷重条件で旧新の上板値は数値誤差内で一致する。最低断面は走査開始側x=0.0137mmでZy=102.742mm³（中実）、98.101mm³（壁1.6mm/40%）。全断面には離れた下側枠も含まれて合成梁の断面係数が非常に大きくなるため、その値を単独で合格根拠にしない。

これは55MPaを仮の曲げ強度とした比較感度で、実スライサの経路、ねじ抜け、局所応力集中、積層異方性、サーボ反力の3次元分配は未確認。力Fと偶力Mを同時に置いた条件も、実シムから取り出した同時反力ではない。SFが2を下回る組合せがあり、実製作の強度・締結確認を省略できない。旧STLも同じ直接上板を持つため、この弱さが今回の切削で新たに発生したとは解釈しない。

再現用コマンド:

```bash
.venv/bin/python tools/inspect_coxa_pocket_candidate.py --before docs/audits/20260905-round2/coxa-before-pocket.stl --after docs/audits/20260905-round2/coxa-pocket-candidate.stl --json /tmp/coxa-pocket-review.json
```

- `coxa-before-pocket.stl`: 天板後端修正後、穴再貫通前の現行STLを保存。
- `coxa-pocket-peer-final.json`: 2形状×全断面/直接上板の全0.2mm走査、6荷重×2印刷近似、全レイ結果と入力hash。
- `coxa-pocket-peer-final.log`: 実行終了0は幾何に限る。`print_strength_status=UNVERIFIED`。
- `tools/tests/test_coxa_sweep.py`: r10の保持面から合法的なサーボ空間を除いても、COXA_REAR_MIN_X=-1の過剰切除を拒否する負例は合格（親担当のfinal回帰ログ）。

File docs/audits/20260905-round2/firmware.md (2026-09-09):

# 第2次 firmware・音声監査 (2026-09-05)

前回の修正確認に加え、実 `main.cpp` をホスト上で実行し、起動・脱力・再通電・入力喪失・I2C故障・校正・電池検知断線を試験した。firmware/src 全12ファイル、platformio.ini、voice_bridge/persona、専用試験・疑似ドライバを通読した記録は `coverage-firmware.json`。GitHub の追跡先は RV-01 #81 (親 #80)。実機へは書き込んでいない。

## 新しく確認し修正した欠陥

| ID / 重要度 | 再現・根拠 | 修正 | 検証 |
|---|---|---|---|
| F2-01 / P1 | 実 Peripherals に7.4V相当→0Vを10秒入力してもcutout=false。平均が3V未満になると3秒判定を解除していた | 一度電池を検知した後の0Vも低電圧停止に含め、復帰しても停止を保持。USBだけの校正時は未検知扱いを維持 (`peripherals.h:56`) | fault試験、実校正main試験 |
| F2-02 / P1 | 実Servosはboard1不在でもsoftStart完了でready=true。PWM書込ACKも無視し、全軸指令を続けた | 設定読戻し、PWM書込ACK、100ms周期のMODE1/prescale監視。不一致で停止保持、健全側も全ch停止、故障側へfull-offを再試行。5ms I2C timeout (`servos.h:109,165,176`) | 起動時不在・瞬間書込失敗・切断/再接続・PCA設定初期化・再起動ボタン再押下を注入 |
| F2-03 / P1 | UI初期standing=trueかつ周期stand:1により脱力後の再読込だけで再通電。通常ファームも起動時自動通電 | 通常版は初期脱力、起動/脱力は明示操作時のみ送信。体高も操作時だけ更新し、再読込で既定値へ戻さない。校正版の自動1500usは維持 (`control.h:9`, `main.cpp:276`, `web_ui.h:111`) | 実setup/loop、実UIスクリプトの初回接続・再接続・体高変更・rest/start |
| F2-04 / P2 | CH_HEADの機構が未確定なのにch12を順次通電し、旋回で±25°出力 | ch12を未使用として全offを維持。可動軸は12脚+6腕+2目の20ch。既存チャンネル番号・機械寸法は変更なし (`servos.h:37`, `main.cpp:302`) | 使用20chとch12/ch25/予備chのoff検査 |
| F2-05 / P2 | 制御接続切断時は1.5秒待ち、期限切れ速度はメールボックスに残った | 最後に完全速度指令を送った接続の切断で速度/PTTを即時0。期限切れ値も0にしmillis周回時の復活を防止 (`main.cpp:50,232`) | 別クライアント切断では継続、所有接続切断では即0、入力喪失でgait停止 |
| F2-06 / P2 | ESP32の16bit mono FIFOには並べ替えの既知制約があるが、DMAをそのままPCMとして扱っていた | 32bit mono DMAへ変更し、PCM16との上下16bit変換を明示。ネットワークのPCM16/16kHzと64BCLKは維持 (`audio.h:33,131`) | 正負の32bitサンプルを元の時系列順のPCM16へ変換する試験。実波形は未検証 |
| F2-07 / P2 | 修正前の実Audio.runに640bytes投入し128bytesの部分書込を返すと512bytes消失。古い再生の終了と次の開始も排他されていなかった | 未送信分を保持。無進捗1秒で再生解除。世代番号と同じロックで旧再生の終了/失敗が新再生を消さないようにした。DMA末尾待機も維持 (`audio.h:131,217`) | 実stepの部分書込、無進捗timeout、旧世代リセット/読出し拒否、DMA待機 |
| F2-08 / P2 | camera関数はMJPEG対応を表明しながらrequests.contentで無限応答の完了待ち。TTSスレッドは無制限キュー・切断後も生成継続 | MJPEGの最初のJPEGだけ取得して閉じる。4MiB・総取得期限・画像形式検査。1byteずつ期限を確認して低速連続応答も検査。TTSキュー16個・取消通知・HTTP応答close (`voice_bridge.py:218,340`) | 初画像後の次フレーム読出し禁止、偽画像/過大画像/低速応答、18チャンク以下で上流停止し取消でclose |
| F2-09 / P3 | DFPlayer要求の読出→0クリア間の競合、負のhistory_turnsで空dequeからpop、personaが測定値を受け取らないことが不明確 | atomic exchange、負値を拒否、実測状態が渡らないことをpersonaに明記 | ビルド、負値試験、全文照合 |

修正前の直接観測は `firmware-before.log`。原稿は `/tmp/tachikoma-firmware-round2-before` に保存して対照した。PWM変換はインストール済み Adafruit PWM Servo Driver 3.0.3 の同じ式と切捨てを使用し、正常時の幅を変更していない。従来の writeMicroseconds は内部prescale読出と書込の失敗を返さないため、検査済みprescaleとACKを返すsetPWMに置き換えた。

ESP32 mono FIFO制約の一次情報は [Espressif I2S仕様](https://docs.espressif.com/projects/esp-idf/en/latest/esp32/api-reference/peripherals/i2s.html)。デバイスは古いAPIを使うArduino 2.0.17/ESP-IDF 4.4系なので、公開仕様に加え、インストール済みdriver/i2s.hのbits_per_chanとDMA定義、Adafruitの実ソースを確認した。SDKを更新する変更はしていない。

## 実行結果

- `firmware-tests.log`: 通常/校正のPlatformIOビルドを含む全実行PASS。通常版RAM 64,400 bytes、Flash 945,181 bytes。
- `firmware-host-final.log`: 最終の5つのC++実行、実UI JavaScript、Python 7試験、実ローカルWebSocket一往復38,400 bytesがPASS。
- C++の正常運動検査は10,000フレーム。gait.h/leg_output.h/config.hの数値・数式は第1次監査から変更せず、シミュレーション担当へ固定を通知した。
- 通常版と校正版それぞれの実setup/loopが、ボード疑似故障・電池検知喪失・停止/再開に応答することを確認。ヘッダーだけの検査には留めていない。
- 全10本の割当ピンは重複なし。ADC34、I2C21/22、I2S26/25/27/33、DFPlayer16/17、LED4。カメラは別基板で、本体のGPIO割当を増やしていない。
- `git diff --check`、Python構文検査を実施。すべてホスト試験とビルドであり、電流や実パルス幅の計測結果ではない。

## 実機確認を残す条件

1. **独立した停止回路**: I2Cが断線/固定された基板のPWMをソフトだけでは消せない。復旧後には停止命令を再送するが、断線中・CPU停止中・再起動完了までのパルス停止は保証しない。OE/電源遮断と保持/転倒を含む既存実機ゲートは未完了。
2. **電圧検知**: 起動時から検知線が未接続の場合とUSBのみはソフトで区別できない。USB校正を維持するため未検知は自動停止対象にしない。実機では電池接続時の表示電圧・分圧配線・停止時間を確認する。
3. **サーボ実測**: 1500usと実角度、ホーン位相、個体の180/270°、JOINT_SIGN、トルク/保持電流、再通電時の実姿勢は測定できていない。softStartは中立角を仮定した順次通電であり、外力で動いた関節を検出する機能ではない。
4. **I2Sと部品実装**: 64BCLK/WS、マイクの左チャンネル選択、MAX98357AのSD結線と左右選択、実音量・歪み・DMA末尾の実時間は未確認。32bit変換のホスト試験は実波形測定の代わりにならない。
5. **実ネットワーク/API**: 本番キーを使うSTT/LLM/TTS・カメラ実機は呼んでいない。HTTP応答待ちの同期スレッドは切断時も直ちに強制終了できず、無応答のread timeoutを待つ場合がある。APIモデル・声ID・契約は別途確認する。
6. **使用基板**: 設定はesp32dev、GPIO16/17を使用。実モジュールがPSRAM搭載WROVER等でこのピンを内部使用する場合の互換性は未確認。実装品の型番を確定する。

併行して購入表のSANWA PM7aに「DC400µ–10A」とある誤記を確認した。[メーカー仕様](https://www.sanwa-meter.co.jp/japan/products/digital_multimeters/pm7a.html)は電圧・抵抗・導通・ダイオードのみで電流機能がない。文書担当へ修正を引き継いだ。

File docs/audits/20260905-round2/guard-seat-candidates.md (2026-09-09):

# 大腿・脛ガードの受け座を設ける有限比較

**全6候補を不採用とする。本流のSTL・CADは変更していない。** 原形ガードをそのまま保ち、支持殻だけに局所受け座を作ると実物の挿入口がない。入口を開放すると見える外面の切除が必要で、脛は可視片が分離する。ガードと骨格の交差も別に残る。

根因は `tools/data/kit_assembly_front.json` の配置最適化が `signed_distance≈+1mm` を目的にし、固体への埋没を「接着に適したフィット」と扱っていたこと。`hardware/src/shell_mod.py` の shin_shell/thigh_cap は、ガード形状を差し引かない。実体積の重複は大腿1211.944mm³（ガードの81.127%）、脛1146.758mm³（77.940%）。過去の頂点埋没率は、組立可能性の判定になっていなかった。

受け座はガードのMinkowski和で作成した。外接二十面体による最小隙間0.10/0.15mmで、最大拡大量は0.126/0.189mm。STL丸めによる退化面を区別するため、元の生成結果と0.01mm簡略化後の両方を保存した。原形ガードは無加工。

| 部品・案 | 保存STLの閉体 / 体数 | 26方向の最良初動最大交差 mm³ | ガード近傍0.2mm外の元外面切除 mm² | 判定 |
|---|---|---:|---:|---|
| 大腿 局所 0.10mm | 閉体 / 1 | 67.772 | 0.0 | 不採用 |
| 大腿 開放 0.10mm | 閉体不成立 / 37 | 0.000 | 724.7 | 不採用 |
| 大腿 局所 0.15mm | 閉体 / 1 | 41.350 | 0.0 | 不採用 |
| 脛 局所 0.10mm | 閉体 / 1 | 163.698 | 0.0 | 不採用 |
| 脛 開放 0.10mm | 閉体不成立 / 12 | 0.000 | 542.5 | 不採用 |
| 脛 局所 0.15mm | 閉体 / 1 | 142.009 | 0.0 | 不採用 |

局所受け座の方向比較は、各軸成分{-1,0,1}からゼロベクトルを除いた26方向、初動0.25/0.5/1.0mm。全方向に正の体積交差がある。これは有限の並進案に対する反証で、回転を組み合わせた全経路の不可能性まで証明していない。

大腿の開放案は+Z方向、脛は+X方向にガード包絡を64mm連続掃引して受け座を開いた例。大腿では上面の約724.7mm²（x7.81..35.22、y−12.06..13.05、z21.82..29.76mm）をガードから0.2mm以上離れて切る。脛では約542.5mm²（x21.09..28.43、y−13.42..12.77、z−105.10..−72.83mm）を切り、CAD上も約283.00mm³の片が本体から分離する。上表のSTL体数には丸め由来の退化面も含まれるが、脛の2体化はCADの実体分解でも再現しており、単なるSTL数値不良とは違う。外面切除の面積・範囲は元メッシュの面中心標本で、全視点の遮蔽面積ではない。

骨格自体は編集していない。ガード–femur交差はFL/RR9.194mm³、FR/RL17.030mm³、ガード–tibiaは全脚約65.413mm³が残る。左右配置は現KITの鏡映とBoolean差が0.000313mm³以下で一致し、一脚だけの座標取り違えではない。

大腿の接着下面z13.1..13.9mmの保存領域では、局所受け座で2.47/3.51mm³、開放案で2.48mm³を失う。脛のM3長穴2箇所はx±6、各z±9、Y全長の比較領域を置き、厳密CAD切削では損失0。STL用簡略化後に約0.085mm³の差が出るため、厳密な材料完全保持とは記載しない。骨格–ガードの交差も残るため、これだけを次の印刷へ移さない。

次の設計では、支持殻を分割してガードを挟み込む方式、原型の接合面を復元した配置、または可視面を変更する量を明示した受け座を比較する必要がある。ガードを切って分割する案は今回対象外。

再現: `tools/design_guard_seat_candidates.py`。表示: `tools/render_guard_seat_candidates.py`。`guard-seat-candidates/comparison.json` が簡略化前、`comparison-final.json` がSTL再読・26方向・左右・支持領域まで含む結果。全STLはリンク座標系の候補専用で、`hardware/stl`へ自動配置しない。接着力・印刷強度・局所壁厚はUNVERIFIED。

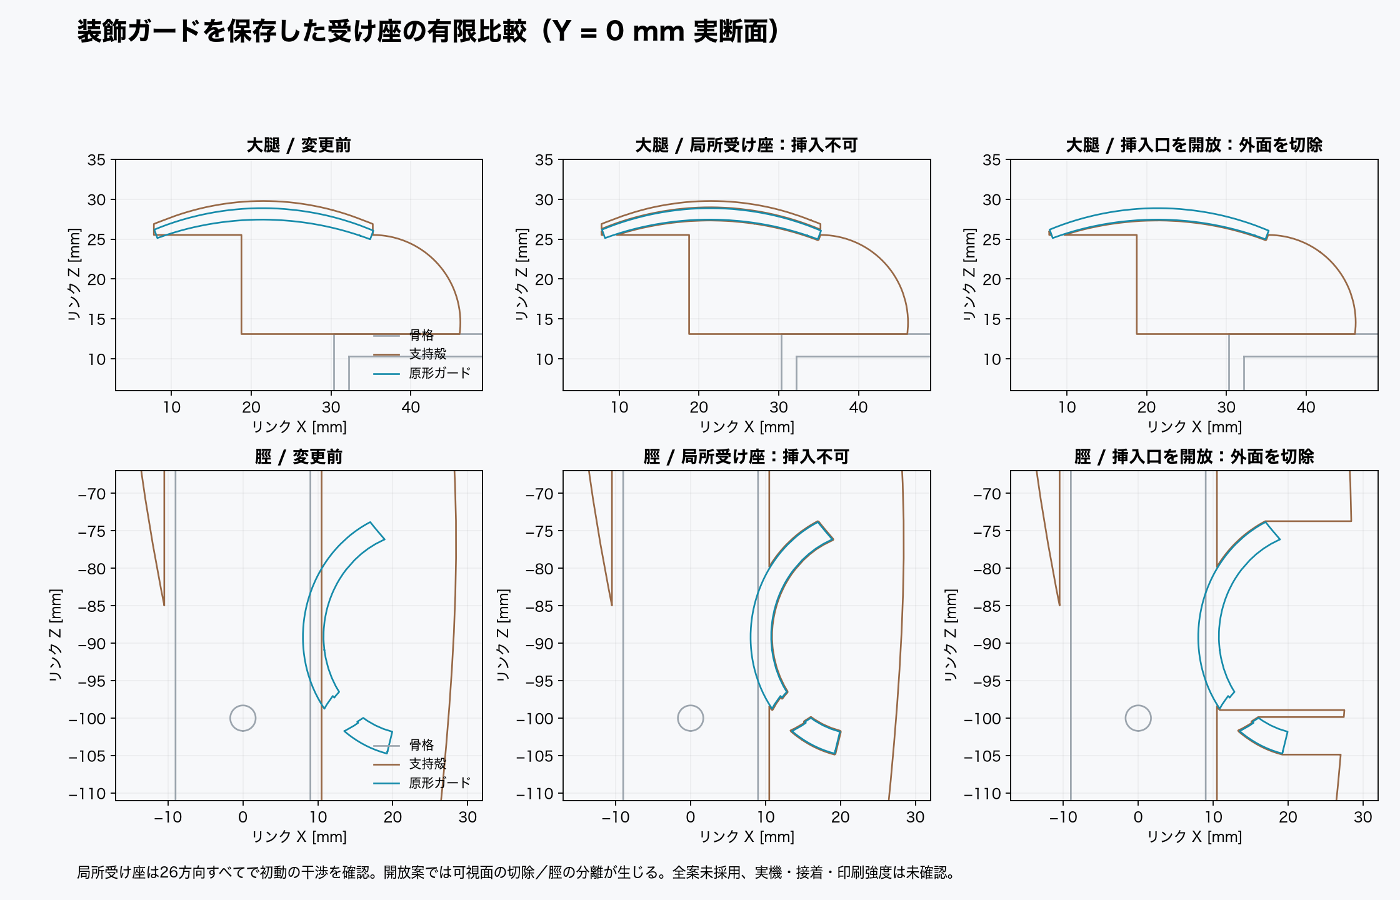
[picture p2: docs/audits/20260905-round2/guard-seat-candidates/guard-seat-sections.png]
実断面による比較


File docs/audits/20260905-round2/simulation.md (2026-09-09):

# 第2次監査：物理シミュレーション・URDF

**現行形状の組立と実機歩行を合格とは判定できない。** 実C++の出力、全パーツの組立変換、固定サーボの占有を加えて調べると、停止保持で部品の実交差がある。床への力も、従来想定のTPUではなく硬いトゥに集中していた。これらを接触除外で隠さず、モデルの誤りは修正し、機構の欠陥と区別した。

最終統合では89条件の動的計算、18姿勢の実メッシュ交差、16回帰を実行し、入力一致を確認した。`stress-before-cad/`、`*-before-final.json`、`before-mouth-clearance/`、`before-stl-repair/` は途中の設計を調べた保存資料で、現在のハッシュ一致を主張しない。特にSIM-12修正前の動的結果は、未更新の派生慣性定数を含むため最終根拠へ流用しない。第1次の [物理監査](../20260905/simulation.md) と動画・10条件は上書きしない。

## 調査範囲と事前の判定基準

担当ソースは `sim_physics.py`、`sim_gait.py`、`export_urdf.py`、`check_urdf.py` と追加した接触・試験・回帰コード。現在のURDF一式、同梱画像、旧7/31フォルダ・8/22ZIPを含め、ファイル単位の読解・解析・実行方法は [coverage-simulation.json](coverage-simulation.json) にSHA-256とともに記録する。

[事前の試験定義](simulation/test-plan.json) は動的試験前に保存した。数値警告なし、roll/pitch各30°以内、股軸の床面からの高さが指令体高の50%以上、IK失敗0、脚以外の床接触0、各脚軸のトルク飽和率5%以下、指令方向へ平均5mm/秒以上、旋回指令方向へ1°以上を既定の比較基準とした。2msと1msの移動距離差5%以内を数値刻みの比較に使う。これらは実機の安全・性能規格ではない。

基本71条件には、前後左右、両方向旋回、複合、急反転、高さ110/115/120/125/130mmと遷移、16位相の停止再開、±5/±10°斜面、2/5/10mm段差、2/5/10N外力、質量・出力・速度・摩擦の感度、60/180秒連続歩行、5/5.5/6V、全リンク/部品/凸分解での自己接触を含む。未採用のTPU靴候補は別の4条件で比較する。

さらに斜面へ本体を予め揃える4条件、未同定の関節補正慣性・粘性・制御ゲインの8条件、その低慣性条件を細かい刻みで確かめる2条件を追加した。それぞれ専用フォルダの `plan.json` に実行前の条件・基準・実行コードのSHAを保存した。身体を斜面へ揃える外部配置を、自動姿勢適応と混同しない。

## 検証器と質量モデルの修正

| 番号 | 再現した問題 | 修正・確認 |
|---|---|---|
| SIM-01 | 実ファームの停止・スルー後ヨー制約・腕の遷移が単純な脚目標計算だけでは再現できない | 実 `Gait/LegOutput/Arms/Servos` をC++ホスト実行し、20軸のPWM量子化後角度・通電状態を50Hzで物理側へ渡す。通信・実IMU・実I/Oはホスト疑似環境の範囲外。 |
| SIM-02 | 高さ115mmで射影した足先のzだけを変えると実ファームの作業空間と不一致 | 高さを `foot_target` の射影前に渡す。親担当の描画も同じ誤りを修正。保持高さ変更の初期姿勢も実C++の115mm保持角から始める。 |
| SIM-03 | サーボ重心が軸付近の概算位置、電装の基準高さ27.6mmが欠落 | タブ下面と軸方向をCADから共用し、ケース側の向き、重心と慣性の回転、電装のHIP_DROPを反映。目の固定タブはポッド背面より6.1mm内側。 |
| SIM-04 | TPUの質量と表示が欠落、未搭載CH_HEADの9gを調整質量として追加、目保持板がPLA既定と概算点位置 | TPUを各足に計上、未搭載9gを削除、目保持板はPETG仕様と実変換後の重心・慣性を使用。実重量と内部密度は未測定。 |
| SIM-05 | 鏡映の二重面反転でFR/RL脛ガードの体積符号が反転 | `apply_transform` が面順を補正する箇所の追加 `invert` を除去。頂点を直接反転する別処理の補正は維持。 |
| SIM-06 | 115mm停止を前後同一角と決めつけ、TPUより低いトゥを接地判定から除外 | `check_urdf.py` を実停止角へ変更。足の硬部最下点とTPU最下点、4脚の同一平面性を検査しNGを終了コード1へ伝える。 |
| SIM-07 | 主ケースと目保持板の衝突形状が無い。MuJoCoの同一base内部は自己衝突でも検出できない | 20主ケース・目保持板を接触診断へ追加。別リンク全AABB候補の実Booleanに加え、同一base内ケースと全部品を実Boolean比較。 |
| SIM-08 | MG90Sの6.6V側トルクを6V上限として流用 | メーカー端点を既存 `POWER_COMPONENTS` へ集約し、運用電圧の直線内挿をURDFと試験で共用。購入個体の同定・6V適合は未確認。 |
| SIM-09 | リンク単位の凸包に硬部とTPUが混在、摩擦1の仮定が全接点へ適用される | 部品別とVHACDを比較。材質ごとの摩擦・柔らかさを設定し、床反力と積分荷重を部品・材料別に保存。地面側の摩擦が優先されないよう接点優先度も指定。 |
| SIM-10 | 発散・自動積分リセット後の姿勢を物理結果に混ぜる危険 | 全MuJoCo警告と非有限値で停止し `NUMERICAL_FAILURE`。初期貫通、転倒、条件不適合は別状態。失敗シナリオの集計は終了コード1。 |
| SIM-11 | 靴候補の慣性をコンパイル後に変えたため、慣性座標に依存する衝突探索境界が古いまま残り、靴が床を抜けた | COMと慣性はMjSpecへ設定してからコンパイルする。0.5秒の支持回帰を追加し、同じ形状・指令で床抜けが消えることを確認。旧4件の失敗は候補の物理的不成立とは扱わず保存。 |
| SIM-12 | コンパイル後の補正慣性・質量変更で、部分木質量と接触用の逆慣性定数が古いまま残る | 質量・慣性・補正慣性・粘性・積分器を全てコンパイル前へ移す。既定と質量1.3倍の再計算差0を確認し、回帰を追加。旧動的結果を最終根拠へ流用せず、全条件を再実行する。 |
| SIM-13 | 凸分解キャッシュのキーに分解条件・実装版がなく、並列生成中の未完了ファイルを読める | 設定とライブラリ版をキーへ含め、一時ファイルから原子的に公開する。途中で書込みを失敗させても既存の完成品が残る回帰を追加。最終試験は先に1本でキャッシュを生成してから並列実行する。 |
| SIM-14 | 非閉殻の入力STLでもURDFへ進め、出力途中の失敗で先に旧メッシュを消す | 個別入力の有限値・閉体・面向き・総体積を検査。負向きの内壁を持つ空洞と複数閉殻は保持する。全出力を一時フォルダで完成し、保存した衝突STLも再検査してから交換。失敗注入で旧一式を保持する回帰を追加。 |

砲身の加工済み `_Bored` 参照、Cabin後半の高さ修正、非採用Head_Plate/Head_Bottom_Cap除外、トゥ150%への倍率修正は親・機構担当の修正と同期して取り込む。

## 実C++と物理モデルの境界

脚目標とスルー後角度の回帰は1563フレーム、各方向・停止再開・高さ変更を含み、Pythonとの最大差は0.000895°だった。別の回帰で20軸の通電順、2秒の起動完了、4.88µsのPWM刻みを確認した。通常起動の初期脱力を、保持姿勢に既に立たせた計算で置き換えない。

MuJoCoは500Hz、C++からの指令は50Hz。各軸の実トルク・最大速度・追従誤差・飽和率、正の機械仕事率の平均/最大/95百分位、10Hzの軸トルクと速度を保存する。軸の無負荷速度を超えて外力で逆駆動されることはあり得るため、速度自体を強制的に切り詰めない。

SIM-11は公式仕様の「剛体内の衝突探索木が慣性座標に沿う」という説明と整合する。候補の質量特性をコンパイル前に確定させ、接触の幾何と探索境界を一緒に構築する。[MuJoCo衝突検出](https://mujoco.readthedocs.io/en/stable/computation/index.html#collision-detection)

SIM-12は [修正前](simulation/derived-mass-constant-reproduction.json) で、質量を1.3倍へ変えた本体の実合計が3.57180kgなのに `body_subtreemass` は2.74754kgのまま、既定でも最初の脚軸の `dof_invweight0` が840.174のまま残り、再計算で442.538へ変わることを再現した。[修正後](simulation/derived-mass-constant-after.json) は関連する全配列について `mj_setConst` 再計算との差が0。コンパイル後のモデル変更を全行見直し、運転中に変える値は速度・通電に応じたアクチュエータの力上限だけにした。

位置制御ゲイン、各関節の粘性0.02、回転慣性補正0.001は未同定の値である。自由ベースへ架空の粘性・慣性は加えていない。印刷質量は体積と表面積の近似、重心・慣性は均質メッシュの仮定。実サーボの連続トルク、電源電圧降下、ホーンや樹脂の変形、バックラッシュ、摩擦、ゴム圧縮・接着強度は未測定で、今回の剛体計算はこれを証明しない。

## 自己衝突：偽接触と実干渉

18姿勢（C++の停止保持指令、機械的0度、歩容16位相）で全候補を出す。主な最終資料は [20ケースの実交差診断](simulation/all-pairs-native-20servos-final.json)。PWM量子化後の指令角に合わせた幾何診断であり、実サーボの角度を測ったものではない。以下の旧交差量は記録時の入力に対するもので、最終形状は末尾の統合試験を参照する。

- 元のリンク凸包では初期の最大侵入が非隣接8.886mm、隣接も含めると24.627mm。単一部品凸包でも19.029mm、VHACDでも10.011mm。凸分解だけで全て消える偽接触ではなかった。
- 実STL同士で、脚付け根の天板前後40.678mm³、シャーシ対thigh_cap/大腿外装、腕の肩対上腕、上腕対前腕、肘殻対前腕などが交差した。修正後の同じ18姿勢では、前後coxa、旧上腕対前腕、旧肘殻対前腕の交差は消失した。残る干渉は末尾に記す。
- 腕はURDF変換を使わない [独立再現](simulation/arm-independent-intersections.json) も行った。旧上腕対前腕は肘0°で598.565mm³、40°で396.104mm³、95°でも36.774mm³。名前や鏡映の誤りではなく、元STLの実交差として機構担当へ渡した。
- 前脚yaw主ケースと目の可動ポッドは約3848/3865mm³、腕肩pitchケースと前脚pitchケースは実C++保持で約413/451mm³交差した。
- 同一baseの内部でも、前脚yawケース対固定目サーボ本体は2033/2457mm³、目保持板は1792/1578mm³交差した。固定ケース対HeadTopも4脚572〜1316mm³、腕100〜106mm³。1つの剛体内部の形状矛盾は、MuJoCoの自己衝突設定では表れない。

旧結果の `Head_Plate` と `Head_Bottom_Cap` は組立で不採用と判明したため、その2部品に対する交差を現仕様の欠陥として数えない。接着面の接触と体積重なりも区別する。印刷した閉じた部品が体積を共有する場合、単に「嵌合予定」として省略せず、必要な逃げ加工・基準面を機構側で確かめる。

VHACDは近似であり、分割数・元体積・凸片体積・入力ハッシュを [キャッシュ台帳](simulation/collision-cache/) に残す。極薄片がMuJoCoで平面と判定される場合は削除せず、元片を全包含する最小厚0.02mmの箱へ置換し、最大追加半厚0.01mm以下を記録する。これも接触形状の近似誤差として扱う。[MuJoCoの接触計算](https://mujoco.readthedocs.io/en/stable/computation/index.html#contact)

## 頭内の4サーボ収納探索

KITのHeadTop/Bottom配置y=12mmとconfigの11mmにも不一致があり、親担当がconfig参照へ統一してから最終URDFを生成した。

正しい向きでは標準サーボ主ケース上面はシャーシ基準で35.2mm、腕サーボは25.5mmになる。旧頭部の仮想ケースが使った18/12mmは、ケースとホーン側を逆に見ており、それぞれ17.2/13.5mm不足していた。

左右対称、原キットの頭外包から1.5mm内側、ケース/他部品間0.6mm、目の位置固定、腕0度/READY、目の固定ケース・保持板、XIAO包絡を条件に、取付XY・ケース向き・タブ高さを有限探索した。外包は元STLの凸包なので収納の必要条件に過ぎない。内部の空隙を凸包で埋める障害物も含み、探索不合格を数学的な収納不能証明とはしない。

旧XIAO予約寸法と、公式STEPから得た余裕込み19.8×25.4×10.5mm・中心(0,42.5,17.75)の更新条件を別資料として保存した。以前、目の固定ケースを省いた広範囲候補は外包だけをほぼ満たしたが、完全占有の候補としては撤回する。

| 条件 | 最良の最大条件違反 | 判断 |
|---|---:|---|
| 取付移動≤10mm、タブ高さ2/−3/−8mmの個別探索 | 9.394 / 11.135 / 13.733mm | 全て不採用 |
| 移動≤5mm、タブ−3mm | 11.153mm | 不採用 |
| 新XIAO包絡、移動≤10mm、高さ−14〜+7mmの連続探索 | 9.544mm、タブ約−0.046mm | 不採用 |
| 新XIAO包絡、広い取付範囲、高さ−14〜+7mm | 5.675mm、タブ約+0.378mm | 不採用 |

元頭外包の最低zは−14.926mmで、1.5mm残厚を保つ最低限の条件でもタブを−13.426mm未満へ下げられない。局所の幅・曲率でさらに制約される。ケースを頭下に露出させる案は外観を変えるため、この比較から採用しない。

[実STLとケース包絡の比較画像](simulation/yaw-packing-comparison.png) / [選択候補の数値](simulation/yaw-packing-comparison.json)。目・保持板・腕ケースは灰、4脚yawケースは橙、XIAOは紫。透過表示は位置関係の説明用で、交差体積は省略前の元メッシュで測る。

元の世界座標足先を保持して新しい軸配置で逆運動学を解いた [比較](simulation/yaw-candidate-ik.json) では、元配置115mmの484点は失敗0。近い変更案でも2点以上の歩容が不可到達になり、大きな内寄せ案はさらに増える。4脚の停止だけが届いても歩容全体を再使用できるとは限らない。タブを下げる案はHIP_DROPとシャーシ支持構造も変わり、現行形状の即時差し替えは行っていない。

## 床支持と電力

形状修正前の材料分離試験では、歩行区間の反力積分約173.7N·sが硬いPLAに載り、TPU反力は0だった。部品単位の凸包でもVHACDでも同じ傾向で、摩擦1を全材質へ与えた場合だけの歩行成功をTPU支持の証明に使えない。さらにトゥ行列100%と印刷150%の不一致が見つかったため、旧トゥでの数値は現仕様の接地量を過小評価している。

TPU靴＋トゥ根元の隠し逃げは機構担当の未採用候補。初回の候補試験はSIM-11の生成器不具合で3 FAIL/1 FALLとなったが、これは無効な物理モデルの結果である。修正前資料は `foot-candidate-before-bvh-fix/` に保存し、判定を採用しない。各脚へ組立行列で移し、追加質量と慣性を反映して4条件を比較する。摩擦・ゴム圧縮・保持強度の実測は別に必要で、外観変更を既定のCADへ自動採用しない。

DS3218の6V内挿最大トルクは約1.956N·m、無負荷速度7.034rad/s。MG90Sは約0.203N·m、13.090rad/s。メーカー資料の端点からの直線内挿であり、実個体の値ではない。MG90Sページは電圧表記に不整合がある。[DS3218資料](https://www.dsservo.com/down.asp?id=22)、[TowerPro MG90S](https://towerpro.com.tw/product/mg90s-3/)

正の機械仕事率は電源入力の理想的な下限の手掛かりで、静止保持時の銅損・駆動回路・電源損失を含まない。6V/10Aの適合は、軸トルクだけから確定せず、親担当の電力感度計算と実電流・温度測定へ引き継ぐ。

## 旧配布物

7/31フォルダと8/22ZIPはそれぞれ78ファイルを全数確認。STLは有限座標・閉じた表面・体積符号、URDFは関節・質量・参照解決、JSONは部品対応、文書は全文、画像は全て表示して確認した。[差分台帳](simulation/old-distributions.json)

旧総質量は7/31が2.863291kg、8/22が2.782693kg。いずれも現在の質量・接地・非採用部品・トゥ倍率・加工済み砲身・Cabin位置の修正を持たない。両側の上腕表示メッシュは、同色の2閉殻を連結してSTL化した境界が非多様体になる既知の例外で、表示の健全性と衝突メッシュの健全性を分けた。旧同梱文書の「前後同一の標準姿勢」「自己衝突OFF推奨」などの記述は現在の根拠に使えない。

元配布物は変更していない。現在フォルダにある旧比較画像2枚も初期SHAと一致する状態で保存し、最新画像は `current-render/` に分けた。現在の [docs/urdf.md](../../urdf.md) は全面更新し、Isaac Simの版・UI既定値の未確認な断定を外した。今回はMuJoCoとホストC++を実行し、Isaac Simでは実行していない。配布物の新旧は更新時刻だけでなく内容ハッシュで確かめる。

## 最終統合試験

2026-09-05 17:18:24 JSTに89条件の動的計算と18姿勢の実交差の完了、条件一致、入力SHA一致、実行中の入力不変を確認した。[最終確認記録](simulation/final_refresh_evidence.json)。最終のURDFは130表示部品、23リンク・20可動関節・2固定関節、推定総質量2.726350kg。実重量は未測定。

| 試験群 | 件数 | 結果と解釈 |
|---|---:|---|
| 基本動的条件 | 71 | 58 PASS、2条件不適合、3転倒、8初期接触モデル無効。数値警告による中断0。 |
| TPU靴候補、水平床 | 4 | 全て条件付きPASS。TPUが受けた床荷重の割合99.79〜99.92%。 |
| 本体を斜面へ予め整列 | 4 | 従来凸包の±10°はPASS。+10°材料別VHACDと靴候補は後退し進行基準FAIL。 |
| 補正慣性・粘性・ゲイン | 8 | 個別基準は全PASS。ただし低補正慣性の2ms計算は移動量の刻み依存が大きい。 |
| 低補正慣性の0.25ms追加 | 2 | 個別基準PASS。0.5msとの移動距離差1.64%/2.22%で5%比較基準を満たす。 |
| 部品の実交差 | 18姿勢 | 停止指令13リンク組、中立15、歩容13〜14。同一base内のケース等12組も残る。Booleanエラー0。 |
| 検証器の回帰 | 16 | 全PASS。実C++脚出力1563フレーム、最大差0.000895°を含む。 |
| URDF検証 | 434項目 | 429 OK、足支持5 NG。構造・FK・慣性等は適合、硬部先行とTPU同一平面性は不適合。 |

[基本71の集計](simulation/scenario_summary.json) / [足候補4の集計](simulation/foot-candidate-summary.json) / [斜面初期配置4](simulation/slope-initialization-final/summary.json) / [関節条件8](simulation/joint-dynamics-final/summary.json) / [追加刻み2](simulation/joint-convergence-final/summary.json) / [16回帰](simulation/regression-final.log) / [URDF検査](simulation/check-urdf-final.log)

水平床の基準条件は6.4秒の歩行区間で0.168142m進み、2msから1msへ刻みを変えた移動距離差は1.285%。180秒の前進指令では3.946707mの進行量を得たが、向きは22.822°変わった。これは実測した直進精度ではなく、今回の姿勢補正なしの計算結果である。

失敗を隠さず個別に見る。床上の中立角から20軸を順次通電する条件は0.454秒で転倒した。外部支持はモデルに含めず、脱力中の実歯車抵抗も未測定である。水平な本体を+10°斜面に投入する条件は0.372秒で転倒した。摩擦0は最終モデルでは数値警告なしで0.070秒に転倒し、旧モデルの数値発散と区別する。出力0.5倍では脚の最大飽和率18.16%、質量1.3倍・出力0.7倍・速度0.75倍・摩擦0.3の複合条件では23.9%となり、5%基準を満たさなかった。

斜面は初期条件を分離した。本体を床角へ揃えると、従来凸包・一様摩擦1では+10°を0.04406m、−10°を0.24808m進んだ。一方、+10°の材料別VHACDでは−0.15702m、靴候補でも−0.02884mとなり、転倒しなくても登坂に成功したとは扱えない。接地形状と材質を分けた比較が必要であり、一様摩擦1の結果を実機の登坂能力へ外挿しない。

低い補正慣性では「警告が出ない」だけで数値精度を十分とはしなかった。補正慣性0.0001/0kg·m²の2ms→0.5msで移動距離が11.26%/17.45%変わったため0.25msまで追加した。0.5ms→0.25msの差は1.64%/2.22%。粗い刻みで出た50.75/59.53Wの瞬間機械仕事率を確定的な電源負荷に使わず、0.25msでは32.42/32.94Wとなることを併記する。これらの比較は実サーボのパラメータ同定を代替しない。

基準条件の正の機械仕事率は平均1.30194W、95百分位4.41483W、最大35.67717W。各軸の平均絶対トルク・最大トルク・速度・飽和率と10Hz時系列をJSONに保存した。静止保持の電流や回路損失はこの値に含まれない。

材料別の現仕様ではTPUの荷重分担は0%。未採用の靴候補を加えると推定質量2.745791kg（約19.44g増）で、水平床4条件はTPU支持95%基準を満たした。靴の保持強度、圧縮特性、実摩擦、外観変更は別に確認する必要がある。

実部品の干渉も残る。停止指令で、左右の肩pitchケース対前脚pitchケースは450.887/412.826mm³、前脚yawケース対目ポッドは3865.024/3847.752mm³、カメラ保持板対HeadTopは0.542mm³。シャーシ対大腿、同じ脚のcoxa対thigh_capも残存する。同一baseでは目の固定サーボ・目保持板・HeadTopと脚yawケースなど12組が重なっている。機械的中立0度では肩ブラケット対腕ガード2.376mm³、腕ガード対シャーシ76.366mm³、coxa対thigh_cap最大363.613mm³もある。機構的な不成立を関節の接触除外で解決したとは扱わない。

[比較図](simulation/simulation-results.png) と [実積分姿勢の動画](simulation/native-nominal-replay.mp4) を保存した。動画は実Gait/LegOutput/Arms/Servosの出力を与えた物理計算の全qposを10Hzで再生するもので、別の近似歩容に置き換えていない。目は中立、実I/O・実IMU応答は対象外。動画の入力一致と元JSONのSHAは [再生記録](simulation/native-nominal-replay.json) にある。自己衝突なし・実干渉残存の注記を動画内にも表示した。最新静止比較は [current-render](current-render/render_urdf_stand.png)、元の履歴PNGは変更していない。

現行設計をそのまま組み立てて実機歩行できるとは判定できない。残る機構修正と現物測定の条件は、上記の失敗内容と未測定項目から判断する。

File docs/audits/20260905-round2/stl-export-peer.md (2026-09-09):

# STL保存処理の独立レビュー

`hardware/src/lib.py::export` と `to_trimesh` を読解し、旧STL保持、空/不正値、法線、閉じた空洞を実際に検査した。本流libの修正は機構担当が実施し、独立担当は `tools/tests/test_export_stl.py` を追加した。最後に重複/ゼロ面を向き変更なしで除去する処理も確認し、実tibiaと空洞への不要面追加の双方で回帰した。

| 内容 | 結果 |
|---|---|
| 正常箱のSTL保存 | 合格 |
| 欠面、空、NaN、Inf、内向き面 | 保存を拒否、旧ファイルのbytes保持 |
| メモリ上は正常な箱がfloat32 STLで潰れる | 保存を拒否、旧ファイル保持 |
| 書込途中の容量不足相当例外 | 同一フォルダの一時ファイルだけが失敗し、旧ファイル保持・一時ファイル削除 |
| 最終os.replaceでの例外 | 旧ファイル保持・一時ファイル削除 |
| 鏡映したManifold | 正しい位置、閉体、外向き、体積24mm³ |
| 独立した2閉体 | 共通exportの既存用途を保って許容。必要な一体制約は部品別検査へ |
| 外箱10³−内箱6³の閉じた空洞 | 修正前1216mm³へ変化、修正後784mm³を保持 |
| 閉体・向き一貫・正体積だが空洞の面向きが誤った1216mm³出力 | sourceの784mm³との不一致を検出して保存拒否 |

新たに再現した根因は `to_trimesh` の `process(validate=True)`。内壁は空洞を表すため負向きだが、各閉曲面を外向きへ直す処理が内壁も反転し、216mm³の空洞を足し算に変えていた。`process=True, validate=False` と未処理の双方では正しい784mm³を保持する。`stl-export-cavity-reproduction.json` に原因を分離した結果を保存。

最終実装はManifoldの面順序を保存し、STL再読後の閉体・面向き一貫・有限頂点・有限正体積を検査する。さらに `abs(STL−Manifold) ≤ 0.01mm³ + 1e-6 × abs(Manifold)` の体積照合を行う。その後、同一フォルダの一時ファイルを完成させてから `os.replace` で出力先を置換する。これにより異常形状だけでなく、途中書込失敗でも旧STLを保持する。

`split()`の面連結数だけで共通exportを一体限定にはしない。閉じた空洞の外壁と内壁も別閉曲面になるため、一般の複数面判定で拒否すると正しい中空体を壊す。独立部品が一つでなければならない条件は部品の設計に従って別途検査する。

実行: `.venv/bin/python -m unittest tools.tests.test_stl_export tools.tests.test_export_stl -v`。機構担当3試験＋独立9試験の12試験すべてPASS。`stl-export-peer-tests.log`は修正前の空洞失敗、`stl-export-peer-tests-final.log`は最終合格。再現は一時フォルダだけを使い、本流STLや実機には書き込んでいない。

この検査は形状とファイル保全を対象とし、全機体の組立可否・印刷強度・電源断時のディスク永続性は認定しない。

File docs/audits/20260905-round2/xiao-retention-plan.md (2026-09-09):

# XIAO・カメラ・FPCの再利用保持案

確認日: 2026-09-06。これは、既存の XIAO ESP32-S3 Sense 一式とカメラ/FPCを買い替えずに使うための独立した候補である。`config.py`、既存 body、assembly、量産 manifest は変更していない。保存済みの測定要約と候補配置から作った包絡・座標・保持台の案であり、現物の型番・改版・FPC長を確定する資料ではない。

機械側は最終形状を凍結した後、[xiao-retention-plan.json](xiao-retention-plan.json) の `build_holder_spec` に最終メッシュ由来の寸法とフレームを渡す。生成した候補STLは量産数へ入れず、最初はトレー1個と基板・カメラ1式だけを適合確認に使う。

## 座標の扱い

保存済みの OV3660 候補には `camera_frame_chassis` と、XIAO候補の `board_frame_flat_to_chassis` が別々にある。古い基板中心 `(0, 45, 23) mm` を現在の頭部へ直接足し込まず、次の順で変換する。

```text
board_to_camera = inverse(camera_frame_chassis) @ board_frame_flat_to_chassis
board_to_base = current_base_camera_frame @ board_to_camera
```

FPCの始点とコネクタ中心も、基板と同じ `inverse(camera_frame_chassis)` を一度だけ適用して camera ローカルへ移す。その後、最終実行時の `A.context(最終設定).camera_mount_frame` を `base_camera_frame` として適用する。したがって、head を 33 mm 上げた後に旧 chassis 絶対座標をそのまま再利用しない。計画JSONに保存した `export_urdf.camera_mount_frame(通常設定)` の値は A.context 外で取得した通常設定の参照値であり、print-first最終フレームではない。頭部・yaw・脚の凍結後に、最終コンテキストから渡したフレームで再生成する。

保存済み候補のカメラフレームは次の通りである。

```text
camera_frame_chassis =
[[-1.000000, 0.000000, 0.000000, 0.000000],
 [ 0.000000, -0.726436, 0.687234, 49.594400],
 [ 0.000000, 0.687234, 0.726436, 29.652800],
 [ 0.000000, 0.000000, 0.000000, 1.000000]]

board_frame_flat_to_chassis =
[[ 0.000000, 1.000000, 0.000000, 0.000000],
 [-1.000000, 0.000000, 0.000000, 45.000000],
 [ 0.000000, 0.000000, 1.000000, 23.000000],
 [ 0.000000, 0.000000, 0.000000, 1.000000]]
```

この候補から得た基板の camera ローカル相対変換は、計画JSONの各 `holder_spec.relative_frames.board_to_camera` に保存している。現行 base への戻し値、FPC始点、コネクタ中心も同じ記録に保存し、旧座標との混同を避ける。

印刷優先構成の保持台は `hardware/src/config.py` の `holder_z_offset_mm = +4.0 mm` を camera ローカル +Z に適用する。適用対象は基板占有、床、左右リブ、holder3一体化候補だけで、既存カメラ子基板・レンズ占有は camera ローカル位置に固定する。FPCはカメラ端を固定し、基板コネクタ端だけを同じ +Z4 mm 移動後の位置として扱う。
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

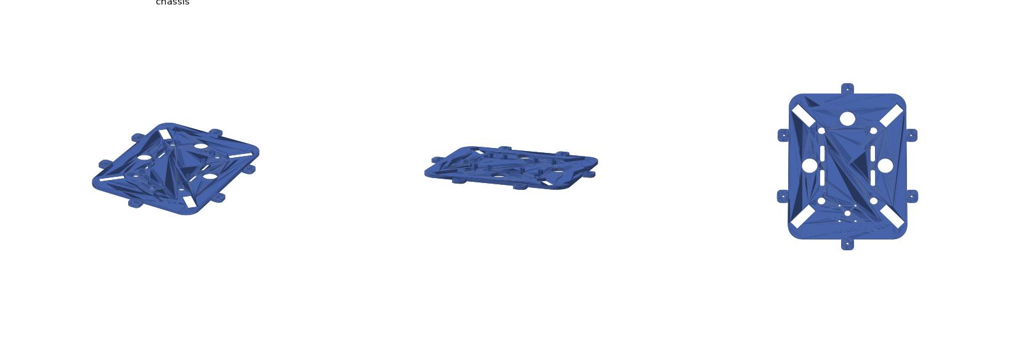
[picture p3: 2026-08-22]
docs/preview_chassis.png

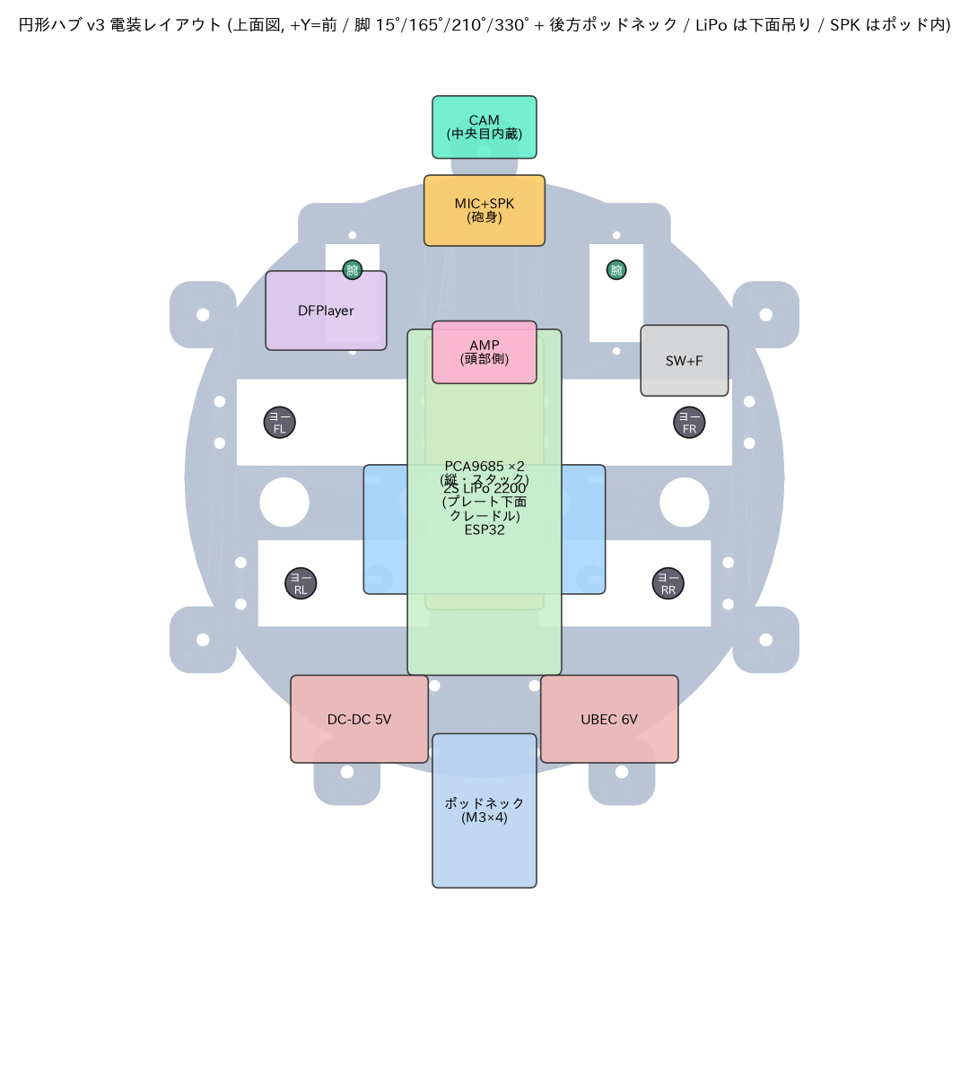
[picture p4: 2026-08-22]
docs/vis_chassis_layout.png

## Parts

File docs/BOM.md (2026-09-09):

# BOM (部品表) — 設計基準と現物照合が必要な構成

**追加購入数は [最新の追加購入一覧](additional-purchases.md) を参照。** 本書の数量は機体の設計必要数であり、手持ちを差し引いた不足数ではない。頭部収納・足裏支持などの改修と購入型番の照合は未完了。

本書の旧概算は約 ¥43,000〜50,300、`docs/shopping.md` の工具等を含む旧購入計画は約 ¥101,400（いずれもフィラメント別）。2026-07 時点の見積りであり、支払済み金額や現在の追加購入額ではない。表の価格も当時の参考値（UNVERIFIED）として扱う。

2026-09-05 の Amazon 注文履歴照合は [追加購入一覧](additional-purchases.md) に集約した。M2.5 ねじ・スタンドオフ等は購入履歴があるため、旧「追加購入」欄をそのまま再注文しない。セット内訳、現物寸法、消耗品残量を確認して不足分を確定する。

## サーボ (レビューで MG92B 案は棄却 — トルク余裕が不足)

| # | 部品 | 数量 | 目安単価 | 用途 / 選定条件 |
|---|---|---|---|---|
| 1 | **DS3218MG (20kg·cm, 270°非対応の180°版)** | 12 | ¥1,500 | 脚全関節 (ヨー4+股ピッチ4+膝4)。**出力軸デュアルボールベアリング必須** (片持ちホーン結合の前提)。同footprintのMG996Rは剛性不足のため不可 |
| 2 | SG90 / MG90S (予備) | 2 | ¥350 | 駆動対象がないためch12は2026-09-05修正版で常時停止。既購入品は予備として保存し、追加購入は不要 |
| 2a | **MG90S (メタルギア)** | 6 | ¥500 | 腕: 肩ヨー2 + 肩ピッチ2 + 肘2。検証済トルク余裕 (肩 1.30/2.2 kg·cm @50g ペイロード)。プラギアの SG90 は不可。**肩ヨー用 2 個は出力軸ボールベアリング品を指定** (腕全体を片持ちで吊り、常時曲げがかかる) |
| 2b | **サブマイクロデジタル (EMAX ES9251II 級, ~0.27〜0.3kg·cm)** | **2** | ¥900 | **目ポッド駆動 ×2** (左右キョロキョロ)。2026-07-29 固定爪化でグリッパ (旧 ×2) を廃止し 4→2 個に削減 (中央目は固定カメラ `eye_pod_camera` で既にサーボ不要)。**6V 耐圧品を指定** (サーボバスは 6V)。寸法は `config.py` SUBMICRO [要実測]。トルクは EMAX 公式・readymaderc・Amazon 出品情報 (確認日2026-07-31) で stall torque 0.25〜0.3kgf·cm@4.8V — `docs/urdf.md` のアクチュエータ表 (0.03N·m≈0.306kgf·cm) と整合する値。旧記載「~0.8kg·cm」は実データと乖離していたため訂正 (2026-07-31) |

- サーボ角範囲: ファーム既定は 500-2500µs/180°。購入品の実仕様に合わせ `firmware/src/config.h` を調整
- 予備 1-2 個の同時購入を推奨 (初期不良・破損対策)。MG90S も 1 個予備推奨

## 電装 (レビューで電源系を全面増強)

| # | 部品 | 数量 | 目安単価 | 用途 / 選定メモ |
|---|---|---|---|---|
| 3 | ESP32 DevKitC (WROOM-32) | 1 | ¥1,500 | 制御 + WiFi AP。**S3 は現行ピン割当と非互換のため不可** (使うなら config.h 全面見直し) |
| 4 | PCA9685 16ch PWM ドライバ | **2** | ¥700 | board0=0x40 (脚12、ch12は予約), board1=0x41 (腕6+目2)。**2 枚目はアドレスジャンパ A0 をハンダ**。信号のみで、**サーボ電源は基板の V+ 端子経由にせず別配線** (下記 wiring.md) |
| 5 | 2S LiPo 2200mAh 35C (XT60) | 1 | ¥3,500 | 設計寸法・重量の基準。容量だけで電流適合を判定せず、放電能力・端子・実電圧降下を確認 |
| 6 | **UBEC 6V/10A** (2S入力) | 1 | ¥1,800 | サーボレール。設計候補HOBBYWING V2は連続10A/瞬間15A、注文メモHENGE 8Aとは別。**接続前に出力6.0Vと各サーボの適合を実測/照合**。9〜14Aは未測定の仮定。電池入力・サーボ側を分けてEL-09で計測し、入力下限・温度・容量を判定 |
| 7 | DC-DC 5V/**3A** (mini560 等) | 1 | ¥500 | ロジック系 (ESP32+LED+DFPlayer)。1A 級は WiFi+LED 全点灯で不足 |
| 8 | **74AHCT125** (レベルシフタ) | 1 | ¥150 (旧参考) | WS2812 DIN の 3.3V→5V 変換 (直結は VIH 仕様外)。裸DIPの電源直近に100nFセラミック1個も必要（[AP-052](additional-purchases.md#ap-052)、手持ち確認） |
| 9 | WS2812B LED (バラ or 短冊) | 12 | ¥500 | メインアイ1 + 頭部左右目2 + 番号維持の隠しLED1 + 赤ランプ8 (隠し1個を抜くと後続番号がずれる) |
| 10 | DFPlayer Mini + microSD | 1 | ¥600 | サウンド (音源はユーザーが用意)。TX へ 1kΩ 直列 |
| 11 | スピーカー φ23〜28mm 8Ω 0.5〜1W | 1 | ¥300 | ボディ内 |
| 12 | メインスイッチ (現物のDC定格を確認) | 1 | ¥250 (旧見積り) | 両DC変換器の入力電流を通す。10Aスイッチ+15Aヒューズは未確定。`wiring.md`の電力換算とEL-09で入力ピーク・DC定格・溶断特性を照合して確定 |
| 13 | 電解コンデンサ 1000µF/16V ×2 + 470µF/10V ×1 | - | ¥200 | サーボレール×2 + 5V レール |
| 14 | XT60 コネクタ, シリコン線 **AWG16**(幹線)/AWG20(分岐)/AWG26(信号) | - | ¥1,500 | AWG20 幹線は不可 (レビュー確認済) |
| 15 | 分圧抵抗 100kΩ + 33kΩ (1/4W) | 各1 | ¥50 | VBAT 監視 (GPIO34) |
| 16 | LiPo 充電器 (2S, バランス充電) | 1 | ¥2,500 | 未所持の場合 |
| 17 | インラインヒューズホルダ + ヒューズ | 1 | ¥300 (旧見積り) | バッテリー直後。既存15A案はEL-09でスイッチ・配線・起動電流との保護協調を確認してから確定 |

## 機械

| # | 部品 | 数量 | 目安 | 用途 |
|---|---|---|---|---|
| 18 | **M3×10 タッピング** | ~70 | ¥700 | STD サーボタブ固定 (4本×12) + **pod_neck 基部 ×4 + battery_cradle フランジ ×4 (v3 追加)** + 予備。下穴 φ2.8 設計 |
| 18b | M3×10 なべ小ねじ + ナット | 4 組 | ¥200 | pod_neck 先端フランジ ⇔ ポッド内側当て板の共締め (v3。シェル貫通穴は現物合わせ) |
| 19 | M3×8 なべ (ホーン中心用は付属品優先) | 12 | ¥300 | ホーン固定ビス (サーボ付属品が合わない場合) |
| 20 | M2×8 タッピング | ~30 | ¥300 | 腕 MG90S タブ固定 (2本×6) + 小物。予備SG90は搭載しない |
| 21 | M2.5×10 | 12 | ¥250 | PCA9685/ESP32 ボス固定 (スタック化 2026-08-22 以降は主に予備 — 下記 21b/21c 参照) |
| 21b | **M2.5×16 M-F スタンドオフ (六角, オスねじ 6mm 程度)** | 4 | ¥300 | **PCA9685 スタック** (2026-08-22 確定): オス側を chassis ボス (下穴 φ2.2) へセルフタップ = board0 (下段) の固定を兼ね、メス側で board1 (上段) を受ける。`docs/wiring.md`「スタック実装の向きルール」参照。**[未購入]** |
| 21c | M2.5×6 なべ | 4 | ¥150 | board1 (上段) → スタンドオフのメス側へ固定。**[未購入]** (M2.5×10 [#21] はスタンドオフのメスねじ深さを超えるため不可) |
| 22 | **M2.6×8 タッピング** | 36 | ¥400 | ホーンアーム穴の共締め: 脚 24 + 腕 (肩ヨー/ピッチ/肘 ×2腕) 12 (アーム穴径は実測して選定) |
| 23 | M3×40 なべ + ナイロンナット | 8 | ¥300 | 脛シェル固定 (2本×4脚) |
| 24 | ベルクロバンド 20mm 幅 | 2 | ¥300 | バッテリー固定 |
| 25 | 結束バンド・スパイラルチューブ | - | ¥400 | 脚・腕配線処理 |
| 29 | 極小タッピング M1.7×6 級 | 6+予備 | ¥200 | **目ポッドのホーン共締め** (2本×2目 — 中央目は固定カメラ目で接着のみ, 2026-07-28 以降)。サブマイクロホーン付属ビスが長さ 6mm 以上あれば流用可。ホーンのアーム穴径に合わせて選定 [要実測] (下穴 φ1.1 設計。#22 の M2.6 は太すぎるので使わない) |
| 35 | 瞬間接着剤 (ゼリー状) またはエポキシ | 少量 | ¥400 | **固定爪の接着継手** (2026-07-29): forearm↔claw_mount (平坦円盤, 突き合わせ), claw_mount↔爪ハブ (Arm_Left_Claw_Grey 近位面, 突き合わせ), 指 (Arm_Left_Finger_Black_x3) ↔ 爪ハブペグ (差込, 圧入+接着併用), 指先チップ (Arm_Left_FingerTip_Grey_x3) ↔ 指根元 (キット標準組立)。物を把持する機構ではない。自重・動作慣性・接着面の剥離は実物で確認する。旧 #26 (手首フランジ M3)/#27 (指ピボットピン M2)/#28 (O リング) は可動グリッパ廃止に伴い不要 |

## 音声会話ユニット (2026-07 追加, `docs/voice.md` 参照)

砲身 (Mouth_Cannon) 内蔵のマイク+スピーカーで、Wi-Fi 経由のブリッジ
(`tools/voice_bridge.py`) と PTT 方式の半二重会話を行うためのモジュール。
I2S0 バス共有 (BCLK=GPIO26, LRCLK=GPIO25, AMP DIN=GPIO27, MIC SD=GPIO33)。
配線は `docs/wiring.md` 参照。

| # | 部品 | 数量 | 目安単価 | 用途 / 選定メモ |
|---|---|---|---|---|
| 30 | **INMP441 I2S MEMS マイクモジュール** | 1 | ¥400 | 砲身内蔵マイク。3.3V 駆動、L/R ピンは GND (左チャンネル固定) |
| 31 | MAX98357A I2Sアンプモジュール | 1 | ¥350 | 5V駆動。Adafruit #3006と互換基板でSD回路が異なるため`wiring.md`の端子仕様を確認。8Ω・1Wスピーカーでは出力音量の制限を実測で決める |
| 32 | **φ20mm 8Ω 1W 薄型スピーカー** | 1 | ¥250 | 砲身内蔵。既存 BOM #11 (ポッド内 DFPlayer 用) とは別個体 |
| 33 | AWG30 シリコン線 (**8芯分**) + 極細コネクタ | - | ¥300 | 頭部↔砲身間のボアを通る配線: マイク 6 芯 (SCK/WS/SD/GND + 3.3V/GND) + スピーカー 2 芯。I2S のアンプ系配線 (基板↔MAX98357A) は頭部内の短距離のみ |

- ロジック電源 (5V/3A DC-DC, BOM #7) から給電。MAX98357A 3W 出力時のピーク
  電流 (~0.6A 見積り) を足しても既存負荷 (ESP32+LED+DFPlayer 実測前見積り
  ~1.7A) との合計は定格内に収まる想定だが、**UNVERIFIED** (実機での電流
  実測が必要。不足する場合のみ #7 を 5V/5A 級へ上位変更)
- マイク・アンプとも 3.3V/5V 系統の**ロジック電源**から給電 (サーボ 6V
  バスとは別系統。詳細は wiring.md)

## カメラユニット (2026-07-28 設計変更: 頭部中央目へ移設, `docs/voice.md` 参照)

**2026-07-28 設計変更**: カメラはポッド (Cabin) のメインアイではなく
**頭部の中央可動目を固定カメラ目に置換したもの** (`eye_pod_camera` +
`camera_carrier`, `hardware/src/make_camera.py`) に内蔵する — 左右 2 目は
キョロキョロ (BOM #2b) を維持。撤去理由: ポッド前面のメインアイ位置は
前方視界の約 80% が自機体 (シャーシ下面/クレードル) に遮蔽されることが
実メッシュ検証 (`robot_meshes(dress=True)` 全アセンブリのレイキャスト) で
判明したため。メイン ESP32-WROOM (脚/腕/頭部制御) は帯域・処理負荷的に
動画を扱わないため、**カメラは完全に独立したモジュールが自前で WiFi
(iPhone インターネット共有) へ接続し MJPEG/静止画 HTTP を配信する**
(本体の PCA9685/I2C バスとは無関係。`tools/voice_bridge.py --camera-url`
が発話のたびに静止画を1枚取得し Anthropic API へ画像として渡す)。
ポッドのメインアイ (`Cabin_Eye_White`) は元パーツのまま無加工で使う。

| # | 部品 | 数量 | 目安単価 | 用途 / 選定メモ |
|---|---|---|---|---|
| 34 | Seeed XIAO ESP32S3 Sense | 1 | ¥2,724 (2026-07-28記録) | 実搭載センサーをP-07で確認。OV2640設計とOV3660を混同しない。カメラ子基板・XIAO本体・FPC・USBを含む収納はH-02で検証。下記2026-09-05訂正を参照 |

**2026-09-05の一次資料確認**: Seeed公開の[OV3660モジュール図面](https://wiki.seeedstudio.com/xiao_esp32s3_getting_started/)は
対角画角102°／水平85°、焦点距離1.63mm±5%、センサー部8×8mm、厚さ5.30mm、FPC込み全長21.20mm。
資料の保存先は`docs/audits/20260905-round2/primary-sources/OV3660_Camera_Module_Specification.pdf`。
現OV2640用の瞳径10mm・レンズ後退6.57mmでは、この画角を満たさない。
対角画角を保つには開口径約16.23mmが必要で、**瞳径10mmを維持する候補はレンズ後退を4.05mm以下へ詰める内部改修**。
現物型番が未確認のため、現行CAM2値をOV3660に置き換えた扱いにはしない。
旧「レンズを外して実測」の手順は撤回し、型番と資料を照合して組立状態で視野を確認する。

| 34b | (代替, 廉価版) AI-Thinker ESP32-CAM | 1 | ~¥1,200 (≈US$13.49) | 基板一体型 40.5x27x4.5mm (カメラがメイン基板から分離できない, 確認日2026-07-28)。**φ37.7 の中央目直後には収まりにくく**、頭部内の別の場所に基板を置いてレンズだけを長めの配線/導光路で持ってくる再設計が必要になる (`hardware/src/make_camera.py` の `camera_carrier`/`eye_pod_camera` は #34 XIAO 側の子基板寸法で設計済み)。安さ優先で自作の再配置をいとわない場合の代替候補。価格出典: AliExpress, 確認日2026-07-28 |

- 給電はロジック 5V (BOM #7) から AWG30 2 芯 (VCC/GND のみ、信号線なし —
  WiFi 接続でメイン基板とは非連携) をシャーシ 7 タブ間隙間から頭部内へ引く
  (頭部は完全固定・可動部なしのため回転部を避ける配慮は不要)
  (`docs/wiring.md` 参照)。XIAO ESP32S3 Sense のカメラストリーミング時消費電流は実測値で
  平均 5V/138mA・瞬間ピーク 5V/341mA の報告あり [出典: OpenELAB Wiki
  (Seeed 公式資料の転載), wiki.openelab.io/seeed-studio/xiao-esp32s3-sense,
  確認日2026-07-28]。既存ロジック負荷 (ESP32+LED+DFPlayer+音声ユニット
  実測前見積り ~2.3A, docs/voice.md 参照) に平均 0.14A を足すと ~2.44A、
  ピーク重畳時は ~2.64A で 5V/3A 定格に対しなお余裕はあるが縮む —
  **UNVERIFIED** (実機での同時稼働時の電流実測が必要。不足する場合は #7 を
  5V/5A 級へ上位変更するか、カメラ用に独立した USB モバイルバッテリー給電
  へ切り替える)
- WiFi 接続は音声ユニットと同じ iPhone インターネット共有 (STA) へ相乗り
  可能。カメラ配信 URL (例 `http://<camera-ip>/capture`) を
  `voice_bridge.py --camera-url` に渡す。プライバシー注意は `docs/voice.md`
  参照

## 印刷材料

→ **docs/filament.md** (色別必要量と購入リスト)

## 設計とひも付く前提 (変更したら再生成)

- サーボ実寸 → `hardware/src/config.py` の STD / MICRO / SUBMICRO プロファイル [要実測]
- ホーン形状 (アーム長/ハブ径/穴位置) → 同 HORN_* [要実測]
- 脚 12 軸が同一サーボなのでスペアの融通が利く。腕 6 軸 (MG90S) も同様

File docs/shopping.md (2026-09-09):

# 買い物リスト — 部品調達 + 工具準備 (2026-07-30 作成)

**追加購入の判断は [2026-09-05の追加購入一覧](additional-purchases.md) を参照。** 以下の旧購入計画には既購入品・予備・現在は不要な部品も含まれ、その全量を追加購入する意味ではない。個数は在庫を照合し、価格・在庫の旧確認日を現在の販売条件と取り違えない。追加印刷は [部品別一覧](additional-printing.md) を使う。

`docs/BOM.md`・`docs/filament.md`・`docs/assembly.md`・`docs/printing.md` を元に、
実発注向けに再構成したリスト。**このファイルが担当範囲であり、BOM.md 本体は
変更していない**。価格・在庫は 2026-07-30 に主要 10 品目以上を実際に
販売ページで確認したが、それ以外は BOM.md の目安値を UNVERIFIED として
そのまま引き継いでいる。

**重要な前提差異 (要確認)**: BOM.md の目安単価の多くは AliExpress 等の
海外クローン品を想定した価格帯に見える。今回「国内優先」の方針で
秋月電子/スイッチサイエンス/Amazon.co.jp の実売価格を確認したところ、
特に MG90S・DFPlayer Mini・INMP441・MAX98357A・PCA9685 (純正) は
BOM.md 想定値の **2〜4倍** だった。下表は国内優先の実勢価格を主に採用し、
AliExpress 相当の目安があれば備考に併記した。

**2026-07-30 追記: 購入先を Amazon.co.jp へ一括集約**。詳細は直下の節を参照。
下表 (A章・B章) はこの集約方針に沿って更新済みであり、以降の価格・小計は
すべて Amazon 集約後の値である。集約前 (秋月電子/スイッチサイエンス/
Strawberry Linux/モノタロウ等が主購入先だった版) の実勢価格は、判明している
範囲で各行に「参考: ○○ ¥xxx (確定)」の形で残してあるため、集約による
価格差はそのまま各行・および D-3 節で確認できる。

---

## 購入先の集約方針 (2026-07-30)

ユーザーからの明示要望:

> 具体的にどのサイトでどの商品を購入したら良いかを指定して教えてください。
> 可能な限り複数のサイトにまたがることは避けたいので、Amazonなどでまとめて
> 買えるなら多少高くなっても構わないので、まとめるようにしてください。

これを受け、8並列の調査エージェントで BOM.md 全36品目 (A-1〜A-5) + フィラメント
(A-6) + 工具一式 (B章) について Amazon.co.jp 上の該当商品を横断調査した
(調査日 2026-07-30)。方針は以下のとおり:

1. **Amazon.co.jp 一括購入を最優先**とする。商品タイトル (可能な場合は
   ページ本文) を WebFetch/ブラウザで照合し、BOM.md の仕様 (型番・寸法・
   定格・角度等) と一致することを確認できた商品を主購入先に採用する。
   価格が秋月電子/スイッチサイエンス/モノタロウ等の従来候補より高くなる
   場合でも、ユーザー方針により Amazon 側を優先する。
2. **Amazon で仕様一致を確認できなかった品目、または Amazon 上に該当商品が
   見つからなかった品目のみ、例外として従来の購入先 (秋月電子等) を維持
   する**。該当は僅少で、D-2 節に一覧化した (WS2812B、φ23-28mmスピーカー、
   φ1.1mmドリル刃、A-5 #18b M3×10なべ小ねじ、TPU95A[Bambu純正が必須の
   場合]の5件)。**[2026-07-30 レビュー指摘対応]** 旧版はここを「3件」、
   D-2節の完全性主張部分を「4件のみ」と記載しており内部で矛盾していた上、
   #18bのなべ小ねじがD-1・D-2いずれの一覧にも未掲載という実際の記載漏れが
   あった。本改訂でD-2になべ小ねじの行を追加し、件数表記を5件に統一した
   (詳細はD-2節・末尾検証節参照)。
3. 発注前のブラウザ目視確認が必要な項目 (JS描画で価格が自動取得できない
   もの、WebFetchでのタイトル照合が失敗し WebSearch スニペットのみに基づく
   もの) は、既存の規律どおり **UNVERIFIED** と明記し、確認済みとは書かない。
4. 既に Amazon 確定リンクだった品目 (DS3218MG・EMAX ES9251II・PCA9685・
   LiPo・UBEC・DC-DC・LiPo充電器・ピンバイスセット・ニッパー・小型バイス・
   ヘルピングハンズ・熱収縮チューブ・LiPoセーフバッグ・グルーガン・
   USBケーブル(Micro-B) の計15行) は変更していない。

---

## A. 購入部品リスト

### A-1. サーボ

| # | 部品 | 数量 (予備込み) | 単価 (税込) | 小計 | 購入先候補 | 確認日 |
|---|---|---|---|---|---|---|
| 1 | **DS3218MG (20kg·cm, 180°, 出力軸デュアルボールベアリング必須)** | 12+2予備=14 | ¥3,089/個 (単品) | ¥43,246 (単品×14) | 単品 [Goolsky DS3218MG](https://www.amazon.co.jp/dp/B07FS9JC2G) ¥3,089/個 ×14 — **既存確定リンク、変更なし** | 2026-07-30 |
| 2 | SG90 / MG90S (2個とも予備。**CH_HEADは予約専用・PWM停止**, `docs/wiring.md`「頭部ヨー (CH_HEAD) の物理対象」参照) | 2 | ¥320/個換算 (JnTech 4個セット¥1,280) | ※#2a と共同購入。下記「MG90S共同購入計画」参照 | [Amazon.co.jp JnTech MG90S 4個セット](https://www.amazon.co.jp/dp/B0CQXGPX8X) ¥1,280/4個。参考: 秋月電子 MG90S ¥1,540/個 (確定) | 2026-07-30 |
| 2a | **MG90S (メタルギア, 腕: 肩ヨー2+肩ピッチ2+肘2)** | 6+1予備=7 | ¥320/個 (JnTech) / ¥366/個 (ICQUANZX, ボールベアリング品) | ※#2 と共同購入。下記「MG90S共同購入計画」参照 | [Amazon.co.jp JnTech MG90S 4個セット](https://www.amazon.co.jp/dp/B0CQXGPX8X) + 肩ヨー2個分は [Amazon.co.jp ICQUANZX MG90S 3個セット (ダブルボールベアリング明記)](https://www.amazon.co.jp/dp/B08DD1VZV2) ¥1,099/3個 を推奨。参考: 秋月電子 MG90S ¥1,540/個 (確定) | 2026-07-30 |
| 2b | **サブマイクロデジタル (EMAX ES9251II級, 6V耐圧, 目ポッド×2)** | 2+1予備=3 | ¥1,641/個 (4g版) | ¥4,923 | [Amazon.co.jp ES9251 II](https://www.amazon.co.jp/dp/B0CK7BM2K4) — **既存確定リンク、変更なし** | 2026-07-30 |

**MG90S (#2+#2a) 共同購入計画 (2026-07-30 Amazon 集約, 必要数合計9個)**:
ICQUANZX 3個セット×1 (¥1,099、肩ヨー2個+予備1個。商品説明本文に
「アルミニウム金属の歯、コアレスモーター、ダブルボールベアリング」と明記されており
BOM.md が肩ヨー2個に指定する出力軸ボールベアリング品の要件に合致) +
JnTech 4個セット×2 (¥2,560、頭部ヨー2個+肩ピッチ2個+肘2個の残り6個をカバー、
2個は追加予備) = **合計 ¥3,659 (11個購入、必要9個+予備2個)**。
JnTech のみで揃える場合は4個セット×3=¥3,840 (12個) でも可だが、その場合
肩ヨー2個のボールベアリング仕様は下記のとおり依然 UNVERIFIED のまま。
いずれの組み合わせでも、旧来の秋月電子 (¥1,540/個×9=¥13,860) より
大幅に安価になる (集約が必ずしも割高にならなかった代表例)。

**サーボ小計: 約 ¥51,800** (DS3218MG ¥43,246 + MG90S共同購入 ¥3,659 + EMAX ¥4,923。
旧小計 ¥62,000 から約 ¥10,200 減 — MG90S の Amazon 価格が秋月電子より
大幅に安かったため)

注意点 (発注前に必ず確認):
- **#1 DS3218MG — 2026-07-30 に主要購入リンクを差し替え済み (旧版の重大な
  不一致を修正)**: 従来この行の主要購入先だった「4個セット」リンク
  (`amazon.co.jp/dp/B07FMBBPD2`) を WebFetch で2回独立に取得し実際の
  商品タイトルを確認したところ、**"DS3218 High Torque Metal Gear Digital
  Servo ... 20kg 270 Degree Rotation ... (Pack of 4 Sets)"** であり、
  (a) 商品名に「MG」表記が無く、(b) 270度仕様だった [出典: amazon.co.jp
  dp/B07FMBBPD2 商品タイトル, 確認日2026-07-30, 2回独立確認]。BOM.md #1
  は「270°非対応の180°版」を明記で要求しており、この4個セットは**不適合
  につき購入対象から除外した**。検索結果には「DS3218」(MG無し, 単一
  ブッシュ軸受)と「DS3218MG」(デュアルボールベアリング)が混在して出て
  くる。**商品名に「MG」表記があり、説明文に「デュアルボールベアリング」
  の記載があるものを選ぶこと** — ただし市場には「ANNIMOS ... DS3218MG
  ... 制御角度270°」のように商品名に「MG」があっても270°仕様の出品も
  実在する [出典: amazon.co.jp 商品名横断検索, 確認日2026-07-30] ため、
  「MG」表記だけでなく**回転角度 (180°) の記載も必ず商品ページ本文で
  確認すること**。今回代替として選定した単品 [Goolsky DS3218MG]
  (https://www.amazon.co.jp/dp/B07FS9JC2G) は商品タイトルに「DS3218MG」
  表記があることを WebFetch で確認済み [確認日2026-07-30] だが、
  ページ本文がJavaScript描画のため回転角度・軸受方式の明記は自動取得
  できず **UNVERIFIED** — 発注前に商品ページを目視で開き、180°表記と
  デュアルボールベアリングの記載を必ず確認すること。信頼できる180°+MG+
  デュアルボールベアリングの4個セット出品は本タスクの調査範囲では
  見つからなかったため、単品×14での購入計画に変更した (バルク割引が
  必要な場合は上記3点を確認できた出品に限り差し替え可)。
  **[2026-07-30 追記, Amazon集約タスクでの再照合]**: 代替候補として
  「BEBK DS3218MG 20kg (180度)」(B096SK4YFP, ¥2,742, 単品売り) を検討したが、
  タイトルは「180度」表記なのに商品説明本文には「270度の回転」という矛盾記載
  があり、上記と同種の危険パターンのため不採用とした。信頼できる180°+MG+
  デュアルボールベアリングのバルクセット出品は今回も見つからず、単品×14の
  既存計画を維持する。
  **[2026-07-30 追記, レビュー指摘対応]**: 上記の「発注前に商品ページを
  目視で確認すること」という指示について、ブラウザで商品ページ本文を
  全文取得し再検証した結果、**商品説明の「仕様」欄 (ブランド/モデル/
  デッドバンド/動作電圧/動作速度/ストールトルク/モータタイプ/ギアの
  タイプ/動作周波数/CE認証/重さ/サイズ) には回転角度 (180°/270°) と
  デュアルボールベアリングの記載がそもそも存在しない**ことを確認した
  [出典: amazon.co.jp/dp/B07FS9JC2G 商品説明全文 (ブラウザ直接レンダリング,
  WebFetchのJS制限を回避), 確認日2026-07-30]。したがって「目視で確認する
  こと」という従来の指示は実行不能であり (確認しようにも当該情報が商品
  ページ自体に存在しない)、以下のいずれかに置き換える: (a) 出品者Q&Aや
  カスタマーレビューで180°・デュアルボールベアリングの実機情報を個別に
  確認する、(b) 発注前に出品者 (kokorest-JP) へ直接問い合わせる、
  (c) タイトル・本文双方に両仕様が明記された代替品へ切り替える。(c)の
  具体候補として、同ページの「関連商品」欄に表示されていた
  [Hiwonder(LewanSoul) 20kg デュアルボールベアリング高トルクフルメタル
  ギア180°デジタルサーボ](https://www.amazon.co.jp/dp/B07CMBMWZW)
  (¥2,900, 4.0/5・83件, 販売元LewanSoul JP/Amazon発送) を確認したところ、
  商品説明の特徴欄に「180 degree rotation. Controllable angle range from
  0 to 180 degrees」および「Dual ball bearing: one is the driving ball
  bearing, one is the assistant ball bearing (support role)」と明記されて
  おり、BOM.md必須要件 (180°・出力軸デュアルボールベアリング) を本文
  レベルで確認できた [出典: amazon.co.jp/dp/B07CMBMWZW 商品説明,
  確認日2026-07-30]。ただしDS3218MG (20kg·cm, 40.5×40×20mm, DSSERVO製)
  とは型番・寸法・トルク仕様 (20kg·cm@6.6V, 40×20×45mm, LewanSoul製) が
  異なる別製品のため、単純な同一品置き換えではなくBOM.md側での仕様許容
  判断が必要 (本タスクはshopping.mdのみ担当のためBOM.md側の判断は行って
  いない)。価格はGoolsky単品 (¥3,089) よりむしろ安い (¥2,900)。発注担当は
  上記(a)〜(c)のいずれかで仕様を確定させてから発注すること。現行の
  単品×14計画 (Goolsky DS3218MG) 自体は本タスクでは変更しないが、
  「目視確認」だけでは仕様確認が完了しない点を明記する。
- **#2a MG90S 肩ヨー用2個 (ボールベアリング仕様)**: 従来 UNVERIFIED
  (秋月電子の標準品がボールベアリング仕様か不明) だった項目。**[2026-07-30
  追記]** Amazon 集約タスクで [ICQUANZX MG90S 3個セット]
  (https://www.amazon.co.jp/dp/B08DD1VZV2) を発見し、商品説明本文の
  「構造材料」欄に「ダブルボールベアリング」の記載があることを確認した。
  ただしこのベアリング記載はタイトルではなく本文のみであり、回転角度も
  本文に「最大90°」(中立から片側、合計180°相当と解釈) との記載のため、
  DS3218MGでの270°誤表記の前例に鑑み、**発注前に商品ページを目視で
  再確認し270°品でないことを必ず確認すること**。3.5/5(40件)のレビューで
  個体差の指摘あり — 品質ばらつきにも留意。
- **#2b サブマイクロ**: 確認した ES9251 II (4g版) のカタログ値はストール
  トルク 4.8V=0.25kgf·cm/6V=0.3kgf·cm 程度で、**BOM.md 記載の
  「~0.8kg·cm」より小さい** [出典: EMAX ES9251II 系の複数販売ページの
  スペック記載, 確認日2026-07-30]。0.8kg·cm 級は近縁機種 ES9051
  (4.1g, 0.8kg·cm) の値に近く、BOM 側で型番と目標トルクの対応関係が
  ズレている可能性がある。目ポッドは無負荷駆動のため 0.25-0.3kgf·cm でも
  動作上問題ない可能性が高いが、**この数値差異は BOM.md 側の確認・修正が
  望ましい** (本タスクは shopping.md のみ担当のため BOM.md は変更していない)。

---

### A-2. 電装

| # | 部品 | 数量 | 単価 (税込) | 小計 | 購入先候補 | 確認日 |
|---|---|---|---|---|---|---|
| 3 | ESP32 DevKitC (WROOM-32E) | 1 | ¥3,500 (確定, 2026-07-30 ブラウザで直接確認。旧記載はUNVERIFIED相場¥2,600〜¥4,524だった) | ¥3,500 | [Amazon.co.jp Espressif ESP32-DevKitC-32E開発ボード](https://www.amazon.co.jp/dp/B087TP5471) (商品タイトルに「32E」表記、商品概要欄に「ESP32-WROOM-32E(4MB)埋め込み。」の記載をブラウザで本文確認 [2026-07-30 レビュー指摘対応で確定]。旧候補 B08926W9NM は "ESP32-WROVER-E開発ボード" というタイトルで別モジュールと判明し除外済み)。参考: 秋月電子 ¥1,800 (確定) | 2026-07-30 (再確認) |
| 4 | PCA9685 16ch PWM ドライバ | 2 | ¥900/個 (2個セット¥1,799) | ¥1,799 | [Amazon.co.jp クローン品2個セット](https://www.amazon.co.jp/dp/B0CZPKTCF6) — **既存確定リンク、変更なし** | 2026-07-30 |
| 5 | 2S LiPo 2200mAh 35C以上 (XT60) | 1 (2個セットで購入し予備確保) | ¥2,250/個 (2個セット¥4,499) | ¥4,499 | [Amazon.co.jp Zeee 7.4V 50C 2200mAh XT60プラグ 2パック](https://www.amazon.co.jp/dp/B0CGWSXL4H) — **既存確定リンク、変更なし** | 2026-07-30 |
| 6 | UBEC 6V/10A (2S入力) | 1 | ¥2,174 | ¥2,174 | [Amazon.co.jp HOBBYWING UBEC-10A-V2](https://www.amazon.co.jp/dp/B0B5694HHF) — **既存確定リンク、変更なし** | 2026-07-30 |
| 7 | DC-DC 5V/3A (mini560等) | 1 (安価なので5個セット購入推奨) | 約¥1,100-1,300/個 (5個セット¥5,500-6,500) | ¥1,300 | [Amazon.co.jp mini560 5V/5A 5個セット](https://www.amazon.co.jp/dp/B09W8LJPF8) — **既存確定リンク、変更なし** | 2026-07-30 |
| 8 | 74AHCT125 (レベルシフタ) | 1 (安価なので予備2-3個推奨) | ¥1,297 (10個入り, ¥1,097+送料¥200) | ¥1,297 | [Amazon.co.jp SN74AHCT125N DIP-14 10個入り](https://www.amazon.co.jp/dp/B0C6H1MPXT) — **旧リンク差し替え**。旧リンク(`amazon.co.jp/dp/B08RX634X5`, 74HCT125系5個入)をブラウザで再照合したところ**現在在庫切れ・再入荷予定なし**と判明し、正確な型番「SN74AHCT125N」がタイトルに明記され在庫ありの本品へ差し替えた | 2026-07-30 |
| 9 | WS2812B (基板モジュール, ピンヘッダ付き) | 12+予備3=15 | ¥70/個 | ¥1,050 | **Amazon非対応 (例外, D-2参照)**。主要候補6品目以上でWebFetchが500/503エラーで失敗し、規定のタイトル照合ができなかったため確定リンクとして提示できず。[秋月電子 WS2812B搭載モジュール](https://akizukidenshi.com/catalog/g/g108414/) を継続使用 | 2026-07-30 (秋月分) |
| 10 | DFPlayer Mini + microSD | 1 | UNVERIFIED (Amazon本体価格未取得。参考値の幅¥991〜2,728と情報の粗さが大きいため、秋月確定価格¥1,280を暫定使用) | ¥1,280 | [Amazon.co.jp DFRobot DFR0299 DFPlayer](https://www.amazon.co.jp/DFRobot-DFR0299-DFPlayer-%E3%83%9F%E3%83%8BMP3%E3%83%97%E3%83%AC%E3%83%BC%E3%83%A4%E3%83%BC%E3%80%82/dp/B089D5NLW1) (型番DFR0299=DFPlayer MiniのDFRobot正規SKUとタイトルで確認、WebFetch2回)。参考: 秋月電子 ¥1,280 (確定) | 2026-07-30 |
| 11 | スピーカー φ23〜28mm 8Ω 0.5〜1W | 1 | ¥300 (BOM想定, 未個別確認) | ¥300 | **Amazon非対応 (例外, D-2参照)**。JAWL『P28-8-1w』(B0CBXZ66C9)ほか候補5品目でWebFetch照合が全て失敗し found=false。Amazon.co.jp / 秋月電子 (規格一致品を要検索) | UNVERIFIED |
| 12 | ロッカースイッチ (10A級) | 1 | UNVERIFIED (実売価格未取得。BOM想定¥250を暫定使用) | ¥250 | [Amazon.co.jp Kiligen 8個セット (LED付, 12V-24VDC/10A)](https://www.amazon.co.jp/Kiligen-8%E5%80%8B12VDC-10A%E9%85%8D%E7%B7%9A%E6%B8%88%E3%81%BF%E3%82%B9%E3%83%8A%E3%83%83%E3%83%97%E3%82%A4%E3%83%B3%E3%83%A9%E3%82%A6%E3%8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) (タイトルに「12V-24VDC/10A」表記を確認。取付穴径は要目視確認) | 2026-07-30 |
| 13 | 電解コンデンサ 1000µF/16V×2 + 470µF/10V×1 | 3個 | ¥4,081 (詰め合わせキット) | ¥4,081 | [Amazon.co.jp HUAREW 24値600個詰め合わせキット](https://www.amazon.co.jp/dp/B088PV5Y6X) (パッケージ内容表に「1000uF----16V」「470uF------10V」の記載を確認, ブラウザで直接取得)。単品売りは乱立していて割高かつ照合の手間が増えるためキットを採用。参考: 秋月電子 ¥200 (BOM想定, 未個別確認) | 2026-07-30 |
| 14a | XT60コネクタ オスメスセット | 一式 (5ペア) | ¥580 | ¥580 | [Amazon.co.jp INIBUD XT60 5ペアセット](https://www.amazon.co.jp/dp/B01GM9IY4Q) (オス5個+メス5個、熱収縮チューブ付属を確認) | 2026-07-30 |
| 14b | シリコン線 AWG16 | 黒赤各1.5m | ¥2,320 | ¥2,320 | [Amazon.co.jp uxcell 16AWGシリコンワイヤー](https://www.amazon.co.jp/dp/B07S5H58PG) (「16awgシリコン撚り線」「252本の0.08mm錫メッキ銅線」を確認。在庫残り1点) | 2026-07-30 |
| 14c | シリコン線 AWG20 | 黒赤各1.5m | ¥1,230 (本体¥650+送料¥580) | ¥1,230 | [Amazon.co.jp 龜旅 20AWGシリコンワイヤー](https://www.amazon.co.jp/dp/B071NHQ648) (「20 AWG」「シリコンのスキン」を確認) | 2026-07-30 |
| 14d | シリコン線 AWG26 | 7色×各10m | ¥3,500 (¥500/色) | ¥3,500 | [Amazon.co.jp Upinva 26AWGシリコンワイヤー7色セット](https://www.amazon.co.jp/dp/B0B14NSX8W) (「26AWGより線」「シリコンラバー電気配線」を確認) | 2026-07-30 |
| 15 | 分圧抵抗 100kΩ + 33kΩ (1/4W) | 各1 | ¥995 (1280本64種類セット) | ¥995 | [Amazon.co.jp VKLSVAN 1280本金属皮膜抵抗器セット](https://www.amazon.co.jp/dp/B08ZJJLG5V) (抵抗値リストに「33KΩ」「100KΩ」両方の記載をブラウザで確認)。参考: 秋月電子 ¥50 (BOM想定, 未個別確認) | 2026-07-30 |
| 16 | LiPo充電器 (2S対応バランス充電器) | 1 | ¥3,999〜¥4,480 | ¥3,999 | [Amazon.co.jp iFormosa iMAX B6 mini互換 (IF-SKYRC-B6MN)](https://www.amazon.co.jp/dp/B0782YTQGB) — **既存確定リンク、変更なし** | 2026-07-30 |
| 17 | インラインヒューズホルダー + 15Aヒューズ | 1 | ¥690 | ¥690 | [Amazon.co.jp オートエージェンシー(Autoagency) 防滴ミニ平型ヒューズホルダー 2個セット (15Aヒューズ付き)](https://www.amazon.co.jp/dp/B019MIFCUS) (「ミニ平型１５Aヒューズ」付きと明記、付属配線1.25sq=AWG16相当を確認)。参考: 秋月電子 ¥300 (BOM想定, 未個別確認) | 2026-07-30 |

**電装小計: 約 ¥34,800** (旧小計 ¥21,500 から約 ¥13,300 増 — 主因は #13 電解
コンデンサキット [+¥3,881]・#14 XT60/シリコン線の個別品目確定 [+¥6,130]・
#3 ESP32 の実勢価格確定 [+¥900, ¥2,600→¥3,500] 等。いずれも Amazon 集約に
より「未特定UNVERIFIED」だった行に具体的な商品と(多くの場合)確定価格が
付いた結果であり、単純な値上がりというより仕様確認の精度向上に伴う実勢
価格の反映。**[2026-07-30 レビュー指摘対応]** #3 ESP32 は従来ミラーサイト
情報からの相場下限¥2,600をUNVERIFIEDのまま暫定採用していたが、ブラウザで
Amazon商品ページ (B087TP5471) を直接確認したところ実売価格は¥3,500
(確定) であり、下限推定より+¥900高かった。電装小計はこの確定値に基づき
再計算した)

注意点 (発注前に必ず確認):
- **#9 WS2812B・#11 スピーカー φ23〜28mm**: Amazon.co.jp 上で候補は複数
  発見したが、いずれも WebFetch でのページタイトル照合が繰り返し
  500/503エラーで失敗し、規定の方法での仕様確認ができなかったため
  Amazon 側は例外として現行購入先 (#9は秋月電子、#11は未特定) を
  維持した。詳細候補は D-2 節を参照。
- **#13 電解コンデンサ**: HUAREW詰め合わせキットは必要数(1000µF/16V×2 +
  470µF/10V×1)を大幅に超える600個・24値入りのため、電装デバッグ用の
  予備部品として他工程にも流用可能。
- **#14 XT60コネクタ・シリコン線**: 単一商品で「XT60+AWG16/20/26全部入り」
  のセット品は見つからず、コネクタ1点+線材3点(AWG別)の計4商品に分割
  購入する形になった。AWG26は必要量(数m程度)に対し70m(7色×10m)と
  大幅に過剰だが、少量小分け出品はAmazon.co.jpでは確認できなかった。
- **#3 ESP32-DevKitC-32E**: 別候補として最初に見つけた
  `amazon.co.jp/dp/B08926W9NM`(『Espressif純正 ESP32-WROVER-E開発ボード
  ESP32-DevKitC-VE』というタイトルの商品)は、WebFetchでタイトル照合した
  結果 **WROVER-E (WROOM-32Eではない別モジュール)** であることが判明し、
  担当品目の仕様に不適合と判断し除外した — DS3218の270°誤リンク事案と
  同種のタイトル不一致を検出できたケース。38pin・Micro-B USB・技適マーク
  の3点はページ本文がJS描画のため未確認 (UNVERIFIED)、発注前に目視確認
  すること。

---

### A-3. 音声会話ユニット (`docs/voice.md` 用, BOM #30-33)

| # | 部品 | 数量 | 単価 (税込) | 小計 | 購入先候補 | 確認日 |
|---|---|---|---|---|---|---|
| 30 | INMP441 I2S MEMSマイクモジュール | 1 | ¥1,617 | ¥1,617 | [Amazon.co.jp DAOKI INMP441 全指向性マイクモジュール](https://www.amazon.co.jp/dp/B0821521CV) (I2S/MEMS/24bit/SN比61dBA/VCC1.8〜3.3V/L・R=GNDで左chをブラウザで本文確認、BOM #30要件と一致)。参考: Strawberry Linux ¥1,100 (確定, Amazon比+47%) | 2026-07-30 |
| 31 | MAX98357A I2S 3Wアンプモジュール | 1 | ¥1,257 | ¥1,257 | [Amazon.co.jp マルツオンライン取扱 Adafruit MAX98357A (型番3006, 正規品)](https://www.amazon.co.jp/dp/B074Z4THWJ) (ブランド/メーカー型番欄でAdafruit純正確認、基板寸法19.4x17.8x3.0mmもAdafruit公式仕様と一致)。参考: スイッチサイエンス ¥1,551 (確定, Amazon比-19%=Amazon側が安い) | 2026-07-30 |
| 32 | φ20mm 8Ω 1W 薄型スピーカー | 1 | ¥1,678 (4個入り) | ¥1,678 | [Amazon.co.jp uxcell 内部磁石スピーカー 4個入り](https://www.amazon.co.jp/dp/B00O9Y3YAQ) (仕様表で直径20mm・総厚2mm・8Ω・1Wを確認、BOM #32要件と完全一致。必要数1個+予備3個確保) | 2026-07-30 |
| 33 | AWG30シリコン線(8芯分)+極細コネクタ(SH1.0) | 一式 | ¥2,998 (線材¥1,693+SH6ピン¥675+SH2ピン¥630) | ¥2,998 | 線材: [Amazon.co.jp BNTECHGO 30AWGシリコンケーブル(赤黒各15.23m)](https://www.amazon.co.jp/dp/B01M7ZBW2X) (「30AWG」「外径0.8mm」「錫メッキ銅より線11本」を確認) / コネクタ(2ピン=スピーカー用): [Amazon.co.jp オーディオファン JST-SH 2ピンコネクタ](https://www.amazon.co.jp/dp/B099W6RJV8) / コネクタ(6ピン=マイク用): 同ブランドの型番違いページ (同一出品ページ内のスタイル選択でSH6ピン/5点セットを選択, ¥675) — **要発注前確認**、6ピン版の独立ASINは今回特定できず | 2026-07-30 |

**音声ユニット小計: 約 ¥7,550** (旧小計 ¥3,200 から約 ¥4,350 増 — #32/#33が
従来UNVERIFIEDの目安値(合計¥550)から具体的な確定価格(合計¥4,676)へ
差し替わったことが主因)

注意点 (発注前に必ず確認):
- **#33**: 付属ケーブルはAWG28でBOM指定のAWG30そのものではなく、マイク側
  (#30)は別途デュポン端子からSH1.0ハウジングへの圧着し直しが必要になる
  可能性が高い。その圧着作業に必要な工具の要否はB章(工具リスト)の担当
  範囲外のため未確認 (UNVERIFIED)。単一商品では『AWG30シリコン線+SH1.0
  コネクタ』のセット品が見つからなかった。当初検討したより網羅的な多ピン
  JST SHキット(YNSSJY/BOJOUL/Xikerswo等)は複数確認したが、いずれも
  在庫切れ・再入荷予定なしのため除外した。

---

### A-4. カメラユニット (BOM #34, #34b)

| # | 部品 | 数量 | 単価 (税込) | 小計 | 購入先候補 | 確認日 |
|---|---|---|---|---|---|---|
| 34 | **Seeed XIAO ESP32S3 Sense (推奨)** | 1 | ¥3,449 (非プレソルダード版) | ¥3,449 | [Amazon.co.jp Seeed Studio XIAO ESP32S3 Sense](https://www.amazon.co.jp/dp/B0C69FFVHH) (販売元Leverage-, Amazonマーケットプレイス/FBA。プレソルダード版は同一商品ファミリーで¥4,000)。参考: スイッチサイエンス ¥2,724 (確定, Amazon比+27%〜+47%) | 2026-07-30 |
| 34b | (代替, 廉価版) AI-Thinker ESP32-CAM | 1 | ~¥1,200 (未再確認) | - | AliExpress — **既存注記、変更なし** | UNVERIFIED (BOM記載の2026-07-28確認を継続採用) |

**カメラユニット小計: 約 ¥3,449** (旧小計 ¥2,700 から約 ¥749 増)

**#34 センサー再確認 (2026-07-30, Amazon版でも継続)**: スイッチサイエンス
商品ページの記載を再確認したところ、依然として「性能向上のためカメラ
センサーをOV3660へ順次アップグレード」の記載が続いており、
**2026-07-30時点でも状況は変わらずOV3660が届く可能性が高い**
[出典: switch-science.com/products/8969, 確認日2026-07-30]。**[2026-07-30
追記]** Amazon側の同一商品ファミリー(プレソルダード版)の実購入者レビュー
(Amazon確認済み購入, 2025年11月付)でも『The ESP32S3 Sense now ships with
a OV3660 camera』との記載があり、Amazon経由の入手でも同じ懸念が当てはまる。
BOM.md #34 の注意書き(OV2640前提のFOV/EFLがOV3660では未確認、実測推奨)は
引き続き有効。また、Amazon上の販売元が『Seeed直販』と明確には確認できない
点もUNVERIFIED。

---

### A-5. 機械部品 (ネジ・接着剤等, BOM #18-25, #29, #35)

**2026-07-30 Amazon 集約についての注記**: 本節の品目は少量・低単価のため、
従来ホームセンターや「Amazon.co.jp (規格一致品を要検索)」という未特定の
表記に留まっていた。今回 Amazon.co.jp 上で具体的な候補商品を発見できたが、
**Amazon.co.jpの商品ページの多くがJavaScript描画のためWebFetchでの本文
照合が繰り返し500エラーとなり**、タイトルレベルの照合に留まる行が多い
(表中の「確認方法」列参照)。価格もほぼ全行がJS描画のため未取得 (UNVERIFIED)
であり、旧来のBOM想定額をそのまま小計に暫定使用している。**発注前に必ず
ブラウザで商品ページを目視確認すること**。

| # | 部品 | 数量 | 目安単価 | 小計 | 購入先候補 | 確認方法・備考 |
|---|---|---|---|---|---|---|
| 18 | M3×10 タッピングビス | ~70+予備 | ¥700 (BOM想定, 暫定使用) | ¥700 | [Amazon.co.jp uxcell M3x10mmステンレスタッピングネジ 100個入り](https://www.amazon.co.jp/dp/B012TI2QRK) | WebSearchスニペットでタイトル確認 (WebFetch本人照合は5回試行しすべて500エラーで失敗)。頭部形状が皿(フラットヘッド)の可能性がありBOM設計(下穴のみ、面取り指定なし)との適合性UNVERIFIED |
| 18b | M3×10 なべ小ねじ + ナット | 4組 | ¥200 (BOM想定, 暫定使用) | ¥200 | ナット: [Amazon.co.jp uxcell ナイロンロックナット M3×0.5mm 100個](https://www.amazon.co.jp/dp/B012T3HNXW) (#23と共用、1パックで12個充足)。なべ小ねじ側は**Amazon非対応 (例外, D-2参照)** — ホームセンターでの汎用品購入を維持 | ナット側はWebFetchでタイトル本人照合済み。小ねじ側はAmazon候補特定できず、数量わずか4本のためホームセンター調達でも実害は小さい |
| 19 | M3×8 なべビス | 12 | ¥300 (BOM想定, 暫定使用) | ¥300 | [Amazon.co.jp Entatial なべ頭小ねじ M3×8](https://www.amazon.co.jp/dp/B09RJMLPJR) | WebSearchスニペットのみ (WebFetch本人照合2回とも500エラーで失敗)。パック内個数UNVERIFIED、サーボ付属品優先のため優先度は低い |
| 20 | M2×8 タッピングビス | ~30 | ¥300 (BOM想定, 暫定使用) | ¥300 | [Amazon.co.jp uxcell M2×8タッピングネジ 100個](https://www.amazon.co.jp/dp/B0779QX67J) | WebSearchスニペットのみ (WebFetch本人照合3回とも500エラーで失敗) |
| 21 | M2.5×10 ビス | 12 | ¥250 (BOM想定, 暫定使用) | ¥250 | [Amazon.co.jp uxcell M2.5×10mm セルフタッピングねじ(真ちゅう) 50個](https://www.amazon.co.jp/dp/B09TSVN2QM) | WebFetchでタイトル本人照合済み (「M2.5x10 mm」「50個」「ラウンドヘッド」を確認) |
| 22 | M2.6×8 タッピングビス | 36 | ¥400 (BOM想定, 暫定使用) | ¥400 | [Amazon.co.jp ねじのトミモリ M2.6×8 なべタッピング 10本入り](https://www.amazon.co.jp/dp/B078K56XZQ) ×4パック=40本 | WebSearchスニペットのみ (WebFetch本人照合3回とも500エラーで失敗) |
| 23 | M3×40 なべビス + ナイロンナット | 8組 | ¥300 (BOM想定, 暫定使用) | ¥300 | ビス: [Amazon.co.jp uxcell M3×40mm パンヘッド機械ネジ 10個入り](https://www.amazon.co.jp/dp/B07PDFH78M) / ナット: #18bと共用(上記B012T3HNXW) | ビス側はWebSearchスニペットのみ (WebFetch3回とも500エラー)。ナット側はWebFetchで本人照合済み |
| 24 | ベルクロバンド 20mm幅 | 2 | ¥300 (BOM想定, 暫定使用) | ¥300 | [Amazon.co.jp マジックバンド 幅20mm×長さ10m](https://www.amazon.co.jp/dp/B0B8XC3ZC4) | WebFetchでタイトル本人照合済み (「幅20mm」「長さ10m」「面ファスナー」を確認) |
| 25 | 結束バンド・スパイラルチューブ | 一式 | ¥400 (BOM想定, 暫定使用) | ¥400 | スパイラルチューブ: [Amazon.co.jp エレコム BST-10 内径10mm×2.0m](https://www.amazon.co.jp/dp/B00008B2XT) / 結束バンド: [Amazon.co.jp 200本入りネジ止め式](https://www.amazon.co.jp/dp/B0D63FN9KS) | 両方ともWebFetchでタイトル本人照合済み |
| 29 | 極小タッピング M1.7×6級 | 6+予備 | ¥200 (BOM想定, 暫定使用) | ¥200 | [Amazon.co.jp 1000Pcsセルフタッピングネジセット (M1/M1.2/M1.4/M1.7)](https://www.amazon.co.jp/dp/B07MW2BLFF) | WebFetchで「M1.7」の記載を確認済み。ただし長さ内訳(6mm相当が含まれるか)はタイトルからは不明 — 発注前に商品ページ詳細で長さ内訳を確認すること |
| 35 | 瞬間接着剤 (ゼリー状) またはエポキシ | 少量 | ¥400 (BOM想定, 暫定使用) | ¥400 | ゼリー状瞬間接着剤: [Amazon.co.jp タミヤ瞬間接着剤(ゼリータイプ)](https://www.amazon.co.jp/dp/B001JJZHI6) / エポキシ: [Amazon.co.jp セメダイン ハイスーパー30 CA-194](https://www.amazon.co.jp/dp/B0CSP78637) | 両方ともWebFetchでタイトル本人照合済み |

**機械部品小計: 約 ¥3,750** (旧小計から変更なし — Amazon側の実売価格が
軒並みJS描画で未取得のため、旧BOM想定額をそのまま暫定使用しているため)

---

### A-6. フィラメント (詳細は `docs/filament.md` 参照)

| 材料/色 | 購入推奨量 | 用途 | 単価目安 (税込) | 購入先候補 | 確認日 |
|---|---|---|---|---|---|
| PLA 青 (マットブルー) | 1kg×2 | Cabin/Head/脚シェル本体色 | ¥3,300〜3,900/kg | [Amazon.co.jp Bambu Lab マットPLA マリンブルー 1kg](https://www.amazon.co.jp/dp/B0CDGSZM75) (タイトルで「マットPLA」「1kg」「マリンブルー」を確認。filament.md指定の「マットブルー」に合致) | 2026-07-30 |
| PLA グレー | 1kg×1 | 関節・砲・足の甲 | ¥3,300〜3,900/kg | [Amazon.co.jp Bambu Lab PLAベーシック グレー 1kg](https://www.amazon.co.jp/dp/B0CGQYMNH9) (色名照合済み。近縁の「シルバー」B0CGR29R63は色違いのため除外) | 2026-07-30 |
| PLA 黒 | 1kg×1 (他用途兼用可) | 指・つま先・インサート | ¥2,800〜3,400/kg | [Amazon.co.jp Bambu Lab PLAベーシック ブラック 1kg (スプールなし)](https://www.amazon.co.jp/dp/B0B2JZ9XL8) (色照合済み。**スプールなし=リフィル品**、既存Bambuスプールへの巻き直しが必要な可能性あり) | 2026-07-30 |
| PLA 白/ナチュラル (LED透光用) | 1kg×1 (他用途兼用可) | 目パーツ (LED透光) | ¥3,300〜3,900/kg | [Amazon.co.jp Bambu Lab PLAベーシック ジェードホワイト 1kg](https://www.amazon.co.jp/dp/B0CGQYRSNT) | 2026-07-30 |
| PLA 赤 | 購入不要でも可 | 赤ランプ (最小量で可) | - | - | - |
| PETG (黒/グレー) | 1kg×1 | 脚・腕骨格・シャーシ・ポッドネック | ¥3,400〜4,300/kg | [Amazon.co.jp Bambu Lab PETGベーシック ブラック 1kg](https://www.amazon.co.jp/dp/B0GS568LQ1) (グレー版B0GS54FRNKも存在、いずれでも可) | 2026-07-30 |
| TPU 95A | 最小巻(500g等)×1、実際は1kg×1で代替 | foot_pad (隠し接地パッド) | ¥3,000〜4,700/kg | [Amazon.co.jp OVERTURE TPU 95A 1kg](https://www.amazon.co.jp/dp/B0BND84XQB) (第三者ブランド、Bambu純正ではない) | 2026-07-30 |

**重要な仕様差異 (#4 PLA白/ナチュラル)**: filament.mdは「半透明のナチュラルが
最も光る」とLED透光性を最重視しているが、Bambu PLA BasicのJade Whiteは
不透明白 (ナチュラル/半透明ではない)。Bambuには別ライン「PLA
Translucent(半透明)」が存在するが、Amazon.co.jp上で色名が明記された該当
ASINは今回特定できなかった。当面はJade Whiteで代用し、eye_pod印刷後の
LED透光具合を実物で確認し、不十分であれば後日 PLA Translucent系への
切替を検討することを推奨する。

**重要な注記 (TPU 95A)**: Amazon.co.jp上でBambu Lab純正のTPU 95A(無印)
またはTPU 95A HFは発見できなかった (Amazon上でBambu純正として見つかった
TPUは「TPU for AMS」硬度68Dのみで、これはB-3が警告するfoot_pad用途の
95Aとは異なる別グレードのため不採用)。上記OVERTURE(第三者製)を暫定採用
するが、RFID自動認識は非対応 (AMSでの手動パラメータ設定が必要)。**Bambu
純正TPU 95A HFが必須の場合はAmazon.co.jpでは確認できず、Bambu Lab公式
ストア (jp.store.bambulab.com) での直接購入が唯一確認できた入手ルート**
— D-2節に例外として記載。いずれにせよB-3節のとおり95A系はAMS直接給紙
不可で外部スプールホルダーによるバイパス給紙が必須。

購入目安合計 (Amazon集約後, 2026-07-30再計算): **約 ¥22,400〜28,000**
(PLA青2kg ¥6,600〜7,800 + PLAグレー1kg ¥3,300〜3,900 + PLA黒1kg
¥2,800〜3,400 + PLA白1kg ¥3,300〜3,900 + PETG黒1kg ¥3,400〜4,300 +
TPU95A1kg ¥3,000〜4,700。旧範囲 ¥12,000〜18,000 から約¥10,000〜10,400増
— Bambu純正フィラメントは一般に汎用PLA/PETGより高価なため)

---

### 概算合計 (A章 部品のみ。工具込みの総合計は末尾「C. 総合計」参照)

| 区分 | 金額 (税込目安) | 旧小計 (集約前) | 差分 |
|---|---|---|---|
| サーボ | ¥51,800 | ¥62,000 | ▲¥10,200 |
| 電装 | ¥34,800 | ¥21,500 | +¥13,300 |
| 音声会話ユニット | ¥7,550 | ¥3,200 | +¥4,350 |
| カメラユニット | ¥3,449 | ¥2,700 | +¥749 |
| 機械部品 (ネジ・接着剤等) | ¥3,750 | ¥3,750 | ±0 |
| **部品小計 (フィラメント別)** | **約 ¥101,400** | ¥93,200 | +¥8,200 (+8.8%) |
| フィラメント | ¥22,400〜28,000 | ¥12,000〜18,000 | +¥10,000〜10,400 |
| **総合計 (フィラメント込み)** | **約 ¥123,800〜129,400** | ¥105,000〜111,000 | +¥18,400〜18,800 (+約17〜18%) |

**注記 (2026-07-30 レビュー指摘対応, 部品小計の丸め方法)**: 部品小計は
各カテゴリ小計 (¥100単位に丸め済み) を単純合算した値ではなく、各行の
生値 (丸め前) を合算してから全体を¥100単位に丸めた値 (サーボ¥51,828+
電装¥34,844+音声¥7,550+カメラ¥3,449+機械部品¥3,750=生値合計¥101,421
→¥101,400)。丸め済みカテゴリ小計 (51,800+34,800+7,550+3,449+3,750)
を単純合算すると約¥101,349になり本小計とは¥50程度異なるが、これは
丸めの順序による差であり計算誤りではない。なお「旧小計」列 (¥93,200等)
も同様に集約前の各カテゴリ丸め値の合算であり、生値ベースとは¥50〜200
程度の差が生じ得るが、この列は本タスク以前に確定していた集約前
ベースラインであり本タスクでは独自の再検証・再計算を行っていない。

**BOM.md記載の概算 (¥43,000〜50,300, フィラメント別) との差異について**:
今回「国内優先」で秋月電子/スイッチサイエンス/Amazon.co.jpの実売価格を
確認した結果、部品小計は BOM.md 記載額の約1.99〜2.33倍になった。主な要因は
(a) MG90S: BOM想定¥500→実勢¥320〜366/個 (BOM想定の約0.64〜0.73倍
程度に圧縮)、(b) DFPlayer Mini正規品: BOM想定¥600→実勢¥1,280 (2倍)、
(c) INMP441: BOM想定¥400→実勢¥1,617 (4倍)、(d) MAX98357A: BOM想定¥350→
実勢¥1,257 (3.6倍)、(e) LiPo充電器: BOM想定¥2,500→実勢¥3,999〜、
(f) DS3218MG: 当初の主要購入計画だった「4個セット」バルク割引 (¥1,500/個
相当) は実際には270°/MG非表記の不適合品と判明したため除外し、適合が
確認できた単品 (¥3,089/個) ×14 に購入計画を切り替えた結果、この1品目
だけで約 +¥22,100 のコスト増となった — これらはいずれも BOM.md 側が
AliExpress クローン品相場や不確認のバルク割引を想定していたためとみられる
(UNVERIFIED: BOM.md 作成時の価格根拠は本タスクでは追跡していない)。

**2026-07-30 Amazon集約後の追加要因**: (g) 電装A-2の#13電解コンデンサ・
#14 XT60/シリコン線・#15分圧抵抗は、従来「Amazon.co.jp(規格一致品を要検索)」
という未特定表記だったものが具体的な確定価格を持つ商品に置き換わり、
合計で約+¥11,000。(h) 音声A-3の#32スピーカー・#33配線一式も同様に
未特定→確定価格化で約+¥4,100。これらは価格上昇というより、従来
UNVERIFIEDだった行の実勢価格が判明した結果である点に留意 (逆にMG90Sの
ようにAmazon側が秋月電子より安かった例もある)。

**予算を圧縮したい場合**: 上記 (a)-(f) を中心に AliExpress 等の海外通販へ
切り替える、または DS3218MG について180°+MG+デュアルボールベアリングの
3点を商品ページ本文で確認できるバルク出品を別途探すことで、
¥20,000〜30,000程度圧縮できる見込み (納期は数週間程度に延びる点に留意)。
詳細は C章「AliExpress節約版」参照。

---

## B. 工具リスト

**2026-07-30 全面改訂**: ユーザーは現時点で**工具を一切所有していない**
(フィラメントと Bambu Lab X2D のみ所有) ため、旧版の「工具名+用途」一覧を
**工具ゼロ前提の購入表**へ全面改訂した。主要12品目以上を WebSearch/WebFetch
で実勢確認済み (確認日2026-07-30)。Amazon.co.jp の商品ページは JavaScript
描画のため価格を自動取得できないものが多く、その場合はモノタロウ等の
静的ページで確認できた実勢価格を採用するか、UNVERIFIEDとして相場目安を
併記した (A章で既に確立した方針を踏襲)。

**2026-07-30 追記 (Amazon集約)**: 本節も A章と同じ集約方針でAmazon候補を
追加調査した。ただしB章はもともと100均・ホームセンター調達を前提とした
安価な消耗品が多く、Amazon候補のWebFetch本人照合が成功した行は限定的
(多くはWebSearchスニペットのみに基づく低確度の候補)。**価格がJS描画で
未取得の行が大半のため、発注前に必ずブラウザで商品ページを目視確認する
こと** (A-5節と同様の注意)。
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

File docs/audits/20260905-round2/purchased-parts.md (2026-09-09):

# 購入済み部品と設計値の照合

2026-09-05。GitHub P-01/P-03の注文メモと現存ファイルを照合した。現物を識別した記録ではない。

| 部品 | 設計・資料 | 注文メモ/現物の状態 | 次に確定する値 |
|---|---|---|---|
| 脚サーボ | DS3218、180°のパルス変換。メーカー資料は4.8–6.8V、180°/270°両品 | LD-20MG×14のメモとLD-220MGの図面が混在。型番未確認 | ケース/タブ/軸/ホーン寸法、角度とパルス、許容電圧、実保持トルク |
| サーボ電源 | HOBBYWING UBEC 10A V2、6V出力、連続10A/瞬間15A | HENGE 8Aの注文メモ。入力下限7Vの記載が2S末期条件と合わない可能性 | 現物型番、入力下限、負荷時出力/温度、5V側との合計入力 |
| 腕・目サーボ | MG90S×6/ES9251II×2 | クローンや別版の定格を一括適用できない | 6V適合、実ケース、ホーン、電流、可動角 |
| カメラ | CAM2既存寸法は旧センサー前提。現行Seeed資料のOV3660は対角102° | XIAO ESP32S3 Senseのセンサー版が未確認 | センサー刻印、子基板8×8×5.30mm、FPC長/幅、主基板とUSBの空間 |
| MAX98357A | Adafruit #3006はSDに基板上プルアップあり | 購入基板の実装が同一か未確認 | SD端子回路、ゲイン設定、8Ω/1Wスピーカーへ許容出力 |
| 電圧計/電流計 | SANWA PM7aは電流測定不可 | PM7aの購入候補を電流計として記載していた箇所を訂正 | 十分な定格のDCクランプ計またはシャント/記録器 |

一次資料: [DS3218](https://www.dsservo.com/down.asp?id=22)、
[LD-220MG](https://www.hiwonder.com/products/ld-220mg)、
[Hobbywing UBEC 10A Car](https://www.hobbywing.com/products/ubec-10a-car79)、
[Seeed XIAO ESP32S3](https://wiki.seeedstudio.com/xiao_esp32s3_getting_started/)、
[MAX98357A #3006](https://learn.adafruit.com/adafruit-max98357-i2s-class-d-mono-amp/pinouts)、
[PM7a](https://www.sanwa-meter.co.jp/japan/products/digital_multimeters/pm7a.html)。

## 電源測定

[測定表](power-measurement.csv)は未記入のひな形。測定結果を仮の値で埋めていない。
サーボ・5V系・電池入力を分けて記録する。計器の帯域/記録周期より短いピークは捕捉できない旨も残す。
入力電流の計算は `(Vservo×Iservo/ηUBEC + Vlogic×Ilogic/ηDC) / Vbat`。
`power-budget.json`は仮定の感度計算であり、実測電流・歩行可能な時間ではない。

無負荷1個、片脚の段階荷重、支持台上の全軸、接地静止、短時間歩行の順に記録する。
サーボ電源は独立スイッチで切れる状態にし、停止時にも機体を支持する。
ヒューズは単に15Aを採用せず、スイッチのDC定格・配線/端子・電池・UBECと溶断時間特性を照合する。
USBから給電している間は外部5Vを切り離す。

I2C故障ではPCA9685が最後のPWMを出し続けるため、通信経由の停止だけでは足りない。
既存スイッチによる独立遮断を実機で確認し、OE回路の追加は配線図と故障時の出力を検証してから採用する。

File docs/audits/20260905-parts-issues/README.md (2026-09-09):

# 購入・印刷・全Issuesの照合（2026-09-05）

前回の監査公開版 `09c4acb` に対して、利用者の依頼に基づき追加購入と追加印刷を整理し、全96課題の現在地・次作業・完了条件・依存を見直した。

**GitHub反映済み（2026-09-05 18:32 JST読戻し）。** 本文96件・タイトル24件、依存156本が計画と一致。担当・11コメント・既存Closed5件を保持した。ProjectのStatus65件と分類24件を更新し、全96件を確認。既存の分類選択肢IDを保持してE9を追加した。[反映結果](publication.json) / [GitHub Project](https://github.com/users/hapx2yuki/projects/2)。

- [追加購入一覧](../../additional-purchases.md): 134品目、Amazon 81商品。80商品は配達表示、PCA9685の2枚セットは注文済み・受領未確認。購入・配達と使用可能在庫を分け、現物不足は未確定とする。
- [追加印刷一覧](../../additional-printing.md): 99 STLと27 3MF。組立基準139個＋元キット予備2個は追加数ではない。今回形状が変わった10ファイル・12個分を以前の未印刷分へ加算しない。配置だけの肘殻2個は再印刷不要。
- [全96課題の見直し](../../issues-audit-20260905.md): 依存173→156（追加23・削除40）。片脚の受入試験と必要な実測を残し、混載プレート全体を待つ不要な依存を外した。既存Closed5件以外は閉じない。

Amazonは認証済みの注文履歴と関連明細・全注文検索を閲覧した。公開するのは本製作に必要な商品名・ASIN・数量・配送状態・確認日だけ。注文番号、住所、支払額、無関係な商品、画面は保存していない。注文、印刷、実機書込みは行っていない。

購入品の型番混在を踏まえ、組立・配線手順も訂正した。通電前に各個体の許容電圧を確認し、1個ずつ中立から段階的に校正する。頭内PCA配置、首接着、足パッド支持を確定済みとは扱わない。裸74AHCT125の電源直近に必要な100nFも購入表・配線図へ反映した。

## 検査記録

- [全体照合](validation.json): 134品目、数量積、99 STLの網羅、196製造ファイルのSHA、139個/変更12個、注文番号等の混入検査。
- [同期前の課題・リンク照合](plan-validation.json): 96本文、1198参照先、固定監査リンク46本の保持。依存は別担当のKahn法でも循環なしを確認。ここに記録したSHAは同期前の確認時点のもの。
- [購入表検算](purchase-validation.log) / [134行の課題対応](purchase-issue-map.tsv)。再実行はリポジトリ直下で `.venv/bin/python docs/audits/20260905-parts-issues/check_purchases.py`。
- [Issue同期回帰9件](issue-sync-tests.log): 重複防止、担当外ラベル・既存状態の保持、不要依存の限定削除、反復実行を確認。

この更新は文書と課題計画の変更。CAD・STL・3MF・URDF・firmwareは変更しておらず、物理シミュレーションを再実行していない。物理検証は[前回の89条件の記録](../20260905-round2/simulation/final_refresh_evidence.json)を参照。今回の台帳照合の合格は、機体の組立・実歩行・現物強度の合格を意味しない。

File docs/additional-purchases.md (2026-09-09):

# 追加調達台帳（公開版、2026-09-06）

この公開版は、現行設計の必要数と現物確認の境界を134項目について示す。
外部記録、商品識別子、現物確認状態などは公開版へ含めない。

## 現行の追加調達計画

今回の着手に必要な追加購入数は **0**。これは実物確認後の不足がゼロだと確定する意味ではない。
各項目の `current_plan` が現行4区分、理由、次の作業を示し、`current_verification_boundary` が現物確認待ちの条件を示す。
`borrow_or_verify` の**30項目**は、在庫・型番・寸法・適合を先に確認する実測対象である。30項目の未確認を購入済み・適合済み・不足0へ読み替えない。
実測ゲートは、対象個体の型番/改版、数量と良品状態、寸法・ねじ・端子、許容電圧/電流、温度・保持・配線経路を記録し、設計・台帳・必要数へ反映してから不足を判定する。

| 区分 | 件数 | 今回の扱い | 次の確認 |
|---|---:|---|---|
| 新print-first採用品 (`print_first_adopted`) | 67 | 現行試作・電装ベンチの使用候補 | 適合、型番、数量、残量、材料、実測を記録 |
| 借用・在庫確認 (`borrow_or_verify`) | 30 | 手持ち・借用・設計整合・実測を先に確認 | 不足確定後だけ必要数を突合 |
| 後回し (`deferred`) | 31 | 初期構成から外す候補を後段へ回す | 基礎試作・組立経路・物理試験後に再評価 |
| 対象外・不採用 (`not_required`) | 6 | 現行構成の対象外 | 再採用時だけ必要数と適合を再評価 |
| 台帳全体 | 134 | 4区分で重複なく分類 | JSON `coverage.classified_once=true` を確認 |

## 全134項目の必要数・判断・現物確認境界

| ID | 品名・仕様 | 必要数 | 区分 | 理由 / 次の作業 | 現物確認境界 |
|---|---|---:|---|---|---|
| AP-001 | **PCA9685用スタンドオフ**<br>M2.5×16 mm M-F、六角胴16 mm、雄ねじ約6 mm | 4 本（現行設計・製作要件） | 借用・在庫確認 | 理由: 旧head/PCAスタンドオフの用途は新head受けの採用設計に依存する。 / 次: mechanicalで新head受けへの使用可否と必要長を確認してから使う。 | 使用可能数=未確認、不足=未確認。現物確認後に更新 |
| AP-002 | **PCA9685上段なべ小ねじ**<br>M2.5×6 mm、スタンドオフ雌ねじの深さ以内 | 4 本（現行設計・製作要件） | 借用・在庫確認 | 理由: 旧head/PCA固定ねじの用途は新head受けの採用設計に依存する。 / 次: AP-001と同時にねじ種・長さ・本数を実物照合する。 | 使用可能数=未確認、不足=未確認。現物確認後に更新 |
| AP-003 | **φ2.2 mmドリル刃**<br>下穴φ2.2 mm | 1 本（使用最低1本。任意の予備1本は別枠） | 借用・在庫確認 | 理由: φ2.2の実工具を確認するまで印刷改修の前提にしない。 / 次: 手持ち/付属品/借用を先に照合し、不足が判明した時だけ最低使用数を更新する。 | 使用可能数=未確認、不足=未確認。現物確認後に更新 |
| AP-004 | **DCクランプ電流計**<br>DC20 A級。旧候補UT210EはDC2/20/100 A、20 Aレンジ分解能0.01 A | 1 台（現行設計・製作要件） | 借用・在庫確認 | 理由: DCクランプ電流計は借用を先にし、購入を着手条件にしない。 / 次: 手持ちまたは借用品の測定範囲・帯域を確認し、無ければ後で必要性を再判断する。 | 使用可能数=未確認、不足=未確認。現物確認後に更新 |
| AP-005 | **DFPlayer用microSD**<br>32 GB以下、FAT16/FAT32。現手順はFAT32 | 1 枚（現行設計・製作要件） | 後回し | 理由: microSDはDFPlayer/SD効果音を後回しにするため初期構成に含めない。 / 次: 手持ち確認だけを行い、初期試作の購入条件にしない。 | 使用可能数=未確認、不足=未確認。現物確認後に更新 |
| AP-006 | **前90度タブ増厚分のねじ**<br>M3系、有効長を従来から+3 mm | 未確定 本（候補未採用） | 後回し | 理由: 初期構成に含めない機能、採用未確定候補、交換候補または旧部品救済。必要性が確定するまで保管し、追加外部記録を先行しない。 / 次: 採用設計または実測の完了後に再評価する。現時点で外部記録・量産・本番搭載をしない。 | 使用可能数=未確認、不足=未確認。現物確認後に更新 |
| AP-007 | **CPUから独立した停止・電源遮断**<br>必要機能1系統、部品の型番・個数未定 | 未確定 式（候補未採用） | 後回し | 理由: 初期構成に含めない機能、採用未確定候補、交換候補または旧部品救済。必要性が確定するまで保管し、追加外部記録を先行しない。 / 次: 採用設計または実測の完了後に再評価する。現時点で外部記録・量産・本番搭載をしない。 | 使用可能数=未確認、不足=未確認。現物確認後に更新 |
| AP-008 | **無負荷試験の機体支持台**<br>脚が床に触れず機体を安定保持 | 1 台（購入は任意・同等手段可） | 借用・在庫確認 | 理由: 手持ち・借用・現物・個体型番・寸法・適合または測定を先に確認する。追加購入は着手条件にしない。 / 次: 先に手持ち/借用/現物と実物条件を記録し、不足が確定した場合だけ採用設計と照合する。 | 使用可能数=未確認、不足=未確認。現物確認後に更新 |
| AP-009 | **電圧/抵抗/導通テスター**<br>DT830B等の実機能・ヒューズを確認 | 1 台（現行設計・製作要件） | 新print-first採用品 | 理由: 現在のprint-first試作・電装ベンチで使う論理部品。現物確認待ち/手持ちを優先するが、外部記録だけで現物適合や残量を確定しない。 / 次: 採用版・必要数をマニフェストと照合し、実物適合/残量を確認してから使用する。 | 使用可能数=未確認、不足=未確認。現物確認後に更新 |
| AP-010 | **表面温度測定手段**<br>サーボ/UBEC/接点の温度を記録 | 1 式（購入は任意・同等手段可） | 借用・在庫確認 | 理由: 手持ち・借用・現物・個体型番・寸法・適合または測定を先に確認する。追加購入は着手条件にしない。 / 次: 先に手持ち/借用/現物と実物条件を記録し、不足が確定した場合だけ採用設計と照合する。 | 使用可能数=未確認、不足=未確認。現物確認後に更新 |
| AP-011 | **質量測定用はかり**<br>部品・全機質量が秤量範囲内 | 1 台（購入は任意・同等手段可） | 借用・在庫確認 | 理由: 手持ち・借用・現物・個体型番・寸法・適合または測定を先に確認する。追加購入は着手条件にしない。 / 次: 先に手持ち/借用/現物と実物条件を記録し、不足が確定した場合だけ採用設計と照合する。 | 使用可能数=未確認、不足=未確認。現物確認後に更新 |
| AP-012 | **瞬間電圧/PWM記録の計器**<br>オシロスコープ/記録計と適合プローブ | 1 式（候補未採用） | 後回し | 理由: 初期構成に含めない機能、採用未確定候補、交換候補または旧部品救済。必要性が確定するまで保管し、追加外部記録を先行しない。 / 次: 採用設計または実測の完了後に再評価する。現時点で外部記録・量産・本番搭載をしない。 | 使用可能数=未確認、不足=未確認。現物確認後に更新 |
| AP-013 | **試験用電流制限電源**<br>対象の電圧/電流に適合するCC/CV電源 | 1 台（候補未採用） | 後回し | 理由: 初期構成に含めない機能、採用未確定候補、交換候補または旧部品救済。必要性が確定するまで保管し、追加外部記録を先行しない。 / 次: 採用設計または実測の完了後に再評価する。現時点で外部記録・量産・本番搭載をしない。 | 使用可能数=未確認、不足=未確認。現物確認後に更新 |
| AP-014 | **microSD読取手段**<br>PCで初期化/音源を書込めるリーダー | 1 個（購入は任意・同等手段可） | 後回し | 理由: microSD読取手段はSD効果音を後回しにするため初期構成に含めない。 / 次: 既存PCスロット/USBリーダーを保管確認し、DFPlayerを再開するときだけ使用可否を判断する。 | 使用可能数=未確認、不足=未確認。現物確認後に更新 |
| AP-015 | **AWG30の被覆処理手段**<br>AWG30対応工具または被覆処理済みリード | 1 式（現行設計・製作要件） | 後回し | 理由: 初期音声配線は現物確認待ちAWG26の直結を先に試すためAWG30専用加工は不要。 / 次: AWG26で成立しない場合だけ配線方式を見直し、必要性を再評価する。 | 使用可能数=未確認、不足=未確認。現物確認後に更新 |
| AP-016 | **本体USBデータケーブル**<br>実ESP32ボードに合うMicro-B | 1 本（現行設計・製作要件） | 新print-first採用品 | 理由: 現在のprint-first試作・電装ベンチで使う論理部品。現物確認待ち/手持ちを優先するが、外部記録だけで現物適合や残量を確定しない。 / 次: 採用版・必要数をマニフェストと照合し、実物適合/残量を確認してから使用する。 | 使用可能数=未確認、不足=未確認。現物確認後に更新 |
| AP-017 | **XIAO用USB-Cデータケーブル**<br>USB-C、保守時にプラグが挿せる外寸 | 1 本（現行設計・製作要件） | 新print-first採用品 | 理由: 現在のprint-first試作・電装ベンチで使う論理部品。現物確認待ち/手持ちを優先するが、外部記録だけで現物適合や残量を確定しない。 / 次: 採用版・必要数をマニフェストと照合し、実物適合/残量を確認してから使用する。 | 使用可能数=未確認、不足=未確認。現物確認後に更新 |
| AP-020 | **脚サーボ**<br>12軸、180度、金属ギア、出力軸支持、適合電圧を実個体で照合 | 12 個（現行設計・製作要件） | 新print-first採用品 | 理由: 現在の脚候補は報告個体LD-220MGだが、対象個体全数の型番・寸法・適合は未照合。 / 次: まず1個を実物照合して片脚試作し、残りを同型と推定せず個体番号を記録する。 | 使用可能数=未確認、不足=未確認。現物確認後に更新 |
| AP-021 | **腕サーボMG90S**<br>肩ヨー2/肩ピッチ2/肘2。肩ヨー2は軸受、全6個の電圧適合確認 | 6 個（現行設計・製作要件） | 新print-first採用品 | 理由: 現在のprint-first試作・電装ベンチで使う論理部品。現物確認待ち/手持ちを優先するが、外部記録だけで現物適合や残量を確定しない。 / 次: 採用版・必要数をマニフェストと照合し、実物適合/残量を確認してから使用する。 | 使用可能数=未確認、不足=未確認。現物確認後に更新 |
| AP-022 | **目用サブマイクロサーボ**<br>ES9251II級、6 V適合、実寸/ホーンを確認 | 2 個（現行設計・製作要件） | 新print-first採用品 | 理由: 現在のprint-first試作・電装ベンチで使う論理部品。現物確認待ち/手持ちを優先するが、外部記録だけで現物適合や残量を確定しない。 / 次: 採用版・必要数をマニフェストと照合し、実物適合/残量を確認してから使用する。 | 使用可能数=未確認、不足=未確認。現物確認後に更新 |
| AP-023 | **CH_HEAD用予備サーボ**<br>ch12は物理駆動対象未定、PWM停止 | 0 個（現行設計・製作要件） | 対象外・不採用 | 理由: 現行print-first構成では購入対象外または不採用。過去の外部記録・不足記録はitems内に保持する。 / 次: 現行構成では用意しない。再採用時に必要数と適合を再評価する。 | 使用可能数=未確認、不足=未確認。現物確認後に更新 |
| AP-024 | **脚付属ホーン/中心ねじ**<br>実スプライン・軸ねじに適合 | 12 組（現行設計・製作要件） | 借用・在庫確認 | 理由: 手持ち・借用・現物・個体型番・寸法・適合または測定を先に確認する。追加購入は着手条件にしない。 / 次: 先に手持ち/借用/現物と実物条件を記録し、不足が確定した場合だけ採用設計と照合する。 | 使用可能数=未確認、不足=未確認。現物確認後に更新 |
| AP-025 | **腕付属ホーン/中心ねじ**<br>MG90S実スプライン・穴ピッチに適合 | 6 組（現行設計・製作要件） | 借用・在庫確認 | 理由: 手持ち・借用・現物・個体型番・寸法・適合または測定を先に確認する。追加購入は着手条件にしない。 / 次: 先に手持ち/借用/現物と実物条件を記録し、不足が確定した場合だけ採用設計と照合する。 | 使用可能数=未確認、不足=未確認。現物確認後に更新 |
| AP-026 | **目付属ホーン/中心ねじ**<br>ES9251II実個体に適合 | 2 組（現行設計・製作要件） | 借用・在庫確認 | 理由: 手持ち・借用・現物・個体型番・寸法・適合または測定を先に確認する。追加購入は着手条件にしない。 / 次: 先に手持ち/借用/現物と実物条件を記録し、不足が確定した場合だけ採用設計と照合する。 | 使用可能数=未確認、不足=未確認。現物確認後に更新 |
| AP-027 | **本体ESP32開発ボード**<br>ESP32-WROOM-32E、現行ピン配置と一致 | 1 枚（現行設計・製作要件） | 新print-first採用品 | 理由: 現行print-firstの本体制御でESP32-WROOM-32E対応ピン配置を使う論理採用品。記録上のと現物確認待ち表示は現物の型番・改版・使用可能状態を証明せず、XIAO ESP32S3 Senseはカメラ専用で本体の代替にはならない。 / 次: 現物確認待ちの1枚を現物照合し、ESP32-WROOM-32E型番、USBデータ通信、電源入力、GPIO配置、基板改版を記録してから本体配線へ接続する。 | 使用可能数=未確認、不足=未確認。現物確認後に更新 |
| AP-028 | **PCA9685基板**<br>2枚、ロジック3.3 V、0x40/0x41 | 2 枚（現行設計・製作要件） | 借用・在庫確認 | 理由: PCA9685は現物確認待ちだが現物未確認で、再外部記録の根拠はない。 / 次: 現物確認と基板実寸・端子を確認してから2枚の用途を確定する。 | 使用可能数=未確認、不足=未確認。現物確認後に更新 |
| AP-029 | **2S LiPo電池**<br>2200 mAh、50 C、XT60、状態/電圧/外寸確認 | 1 個（現行設計・製作要件） | 新print-first採用品 | 理由: 現在のprint-first試作・電装ベンチで使う論理部品。現物確認待ち/手持ちを優先するが、外部記録だけで現物適合や残量を確定しない。 / 次: 採用版・必要数をマニフェストと照合し、実物適合/残量を確認してから使用する。 | 使用可能数=未確認、不足=未確認。現物確認後に更新 |
| AP-030 | **6 Vサーボ用UBEC**<br>2S全使用電圧範囲、実出力6 V、連続電流/温度を確認 | 1 台（現行設計・製作要件） | 新print-first採用品 | 理由: 現在のprint-first試作・電装ベンチで使う論理部品。現物確認待ち/手持ちを優先するが、外部記録だけで現物適合や残量を確定しない。 / 次: 採用版・必要数をマニフェストと照合し、実物適合/残量を確認してから使用する。 | 使用可能数=未確認、不足=未確認。現物確認後に更新 |
| AP-031 | **5 Vロジック用DC-DC**<br>実5 V、設計3 A以上、負荷/温度/ノイズ確認 | 1 台（現行設計・製作要件） | 新print-first採用品 | 理由: 現在のprint-first試作・電装ベンチで使う論理部品。現物確認待ち/手持ちを優先するが、外部記録だけで現物適合や残量を確定しない。 / 次: 採用版・必要数をマニフェストと照合し、実物適合/残量を確認してから使用する。 | 使用可能数=未確認、不足=未確認。現物確認後に更新 |
| AP-032 | **LED信号レベル変換IC**<br>SN74AHCT125 DIP14、5 V駆動 | 1 個（現行設計・製作要件） | 後回し | 理由: LEDを初期構成から外すため信号変換ICは保管扱い。 / 次: LED構成を再開するときだけAP-033/AP-051と一緒に確認する。 | 使用可能数=未確認、不足=未確認。現物確認後に更新 |
| AP-033 | **WS2812B**<br>信号順を維持する12灯、隠し1灯を含む | 12 個（現行設計・製作要件） | 後回し | 理由: WS2812Bは初期発光を後回しにし、購入を開始条件にしない。 / 次: LEDを再開する時点で必要数と手持ちを照合する。 | 使用可能数=未確認、不足=未確認。現物確認後に更新 |
| AP-034 | **DFPlayer Mini**<br>DFRobot DFR0299 | 1 枚（現行設計・製作要件） | 後回し | 理由: DFPlayer本体は既存品として保管するが、初期I2S音声の開始条件にしない。 / 次: microSDと音声機能を再開する時に動作と配線を確認する。 | 使用可能数=未確認、不足=未確認。現物確認後に更新 |
| AP-035 | **DFPlayer用ボディスピーカー**<br>設計φ23〜28 mm、8 Ω、0.5〜1 W | 1 個（現行設計・製作要件） | 後回し | 理由: DFPlayer用ボディスピーカーはSD効果音とボディ保持の後段候補。口用スピーカーの在庫と二重計上しない。 / 次: 初期片脚/電装ベンチ後に保持と音量を測り、AP-056の共有在庫を差し引いて判断する。 | 使用可能数=未確認、不足=未確認。現物確認後に更新 |
| AP-036 | **メインスイッチ**<br>電池側の実電流と開閉条件に合うDC定格 | 1 個（現行設計・製作要件） | 新print-first採用品 | 理由: 現在のprint-first試作・電装ベンチで使う論理部品。現物確認待ち/手持ちを優先するが、外部記録だけで現物適合や残量を確定しない。 / 次: 採用版・必要数をマニフェストと照合し、実物適合/残量を確認してから使用する。 | 使用可能数=未確認、不足=未確認。現物確認後に更新 |
| AP-037 | **ヒューズホルダー**<br>電池直後、幹線/端子定格に適合 | 1 本（現行設計・製作要件） | 新print-first採用品 | 理由: 現在のprint-first試作・電装ベンチで使う論理部品。現物確認待ち/手持ちを優先するが、外部記録だけで現物適合や残量を確定しない。 / 次: 採用版・必要数をマニフェストと照合し、実物適合/残量を確認してから使用する。 | 使用可能数=未確認、不足=未確認。現物確認後に更新 |
| AP-038 | **ヒューズ**<br>ホルダー規格・保護協調・時間電流特性が一致 | 1 個（現行設計・製作要件） | 新print-first採用品 | 理由: 現在のprint-first試作・電装ベンチで使う論理部品。現物確認待ち/手持ちを優先するが、外部記録だけで現物適合や残量を確定しない。 / 次: 採用版・必要数をマニフェストと照合し、実物適合/残量を確認してから使用する。 | 使用可能数=未確認、不足=未確認。現物確認後に更新 |
| AP-039 | **サーボ電源電解コンデンサ**<br>1000 µF/16 V以上 | 2 個（現行設計・製作要件） | 新print-first採用品 | 理由: 現在のprint-first試作・電装ベンチで使う論理部品。現物確認待ち/手持ちを優先するが、外部記録だけで現物適合や残量を確定しない。 / 次: 採用版・必要数をマニフェストと照合し、実物適合/残量を確認してから使用する。 | 使用可能数=未確認、不足=未確認。現物確認後に更新 |
| AP-040 | **5 V電源電解コンデンサ**<br>470 µF/10 V以上 | 1 個（現行設計・製作要件） | 新print-first採用品 | 理由: 現在のprint-first試作・電装ベンチで使う論理部品。現物確認待ち/手持ちを優先するが、外部記録だけで現物適合や残量を確定しない。 / 次: 採用版・必要数をマニフェストと照合し、実物適合/残量を確認してから使用する。 | 使用可能数=未確認、不足=未確認。現物確認後に更新 |
| AP-041 | **XT60コネクタ**<br>極性/接点/線径が合うオス/メス | 未確定 対（現行設計・製作要件） | 新print-first採用品 | 理由: 現在のprint-first試作・電装ベンチで使う論理部品。現物確認待ち/手持ちを優先するが、外部記録だけで現物適合や残量を確定しない。 / 次: 採用版・必要数をマニフェストと照合し、実物適合/残量を確認してから使用する。 | 使用可能数=未確認、不足=未確認。現物確認後に更新 |
| AP-042 | **AWG16線**<br>電池/UBEC幹線、赤黒 | 未確定 m（現行設計・製作要件） | 新print-first採用品 | 理由: 現在のprint-first試作・電装ベンチで使う論理部品。現物確認待ち/手持ちを優先するが、外部記録だけで現物適合や残量を確定しない。 / 次: 採用版・必要数をマニフェストと照合し、実物適合/残量を確認してから使用する。 | 使用可能数=未確認、不足=未確認。現物確認後に更新 |
| AP-043 | **AWG20線**<br>電源分岐、赤黒 | 未確定 m（現行設計・製作要件） | 新print-first採用品 | 理由: 現在のprint-first試作・電装ベンチで使う論理部品。現物確認待ち/手持ちを優先するが、外部記録だけで現物適合や残量を確定しない。 / 次: 採用版・必要数をマニフェストと照合し、実物適合/残量を確認してから使用する。 | 使用可能数=未確認、不足=未確認。現物確認後に更新 |
| AP-044 | **AWG26線**<br>信号用、7色 | 未確定 m（現行設計・製作要件） | 新print-first採用品 | 理由: 現在のprint-first試作・電装ベンチで使う論理部品。現物確認待ち/手持ちを優先するが、外部記録だけで現物適合や残量を確定しない。 / 次: 採用版・必要数をマニフェストと照合し、実物適合/残量を確認してから使用する。 | 使用可能数=未確認、不足=未確認。現物確認後に更新 |
| AP-045 | **AWG30線**<br>音声8芯分+カメラ給電2芯分 | 未確定 m（現行設計・製作要件） | 後回し | 理由: 初期音声配線はAWG26直結を優先し、AWG30線は採用未確定。 / 次: AWG26で成立しない配線箇所が確定した時だけ使用可否を確認する。 | 使用可能数=未確認、不足=未確認。現物確認後に更新 |
| AP-046 | **サーボ電源外部分配部材**<br>20軸(脚12+腕6+目2)の6 V/GND分岐 | 未確定 式（現行設計・製作要件） | 新print-first採用品 | 理由: 現在のprint-first試作・電装ベンチで使う論理部品。現物確認待ち/手持ちを優先するが、外部記録だけで現物適合や残量を確定しない。 / 次: 採用版・必要数をマニフェストと照合し、実物適合/残量を確認してから使用する。 | 使用可能数=未確認、不足=未確認。現物確認後に更新 |
| AP-047 | **サーボ延長/中継配線**<br>実コネクタ/極性/電流に適合 | 未確定 本（現行設計・製作要件） | 借用・在庫確認 | 理由: 手持ち・借用・現物・個体型番・寸法・適合または測定を先に確認する。追加購入は着手条件にしない。 / 次: 先に手持ち/借用/現物と実物条件を記録し、不足が確定した場合だけ採用設計と照合する。 | 使用可能数=未確認、不足=未確認。現物確認後に更新 |
| AP-048 | **VBAT分圧抵抗**<br>100 kΩ、1/4 W | 1 本（現行設計・製作要件） | 新print-first採用品 | 理由: 現在のprint-first試作・電装ベンチで使う論理部品。現物確認待ち/手持ちを優先するが、外部記録だけで現物適合や残量を確定しない。 / 次: 採用版・必要数をマニフェストと照合し、実物適合/残量を確認してから使用する。 | 使用可能数=未確認、不足=未確認。現物確認後に更新 |
| AP-049 | **VBAT分圧抵抗**<br>33 kΩ、1/4 W | 1 本（現行設計・製作要件） | 新print-first採用品 | 理由: 現在のprint-first試作・電装ベンチで使う論理部品。現物確認待ち/手持ちを優先するが、外部記録だけで現物適合や残量を確定しない。 / 次: 採用版・必要数をマニフェストと照合し、実物適合/残量を確認してから使用する。 | 使用可能数=未確認、不足=未確認。現物確認後に更新 |
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

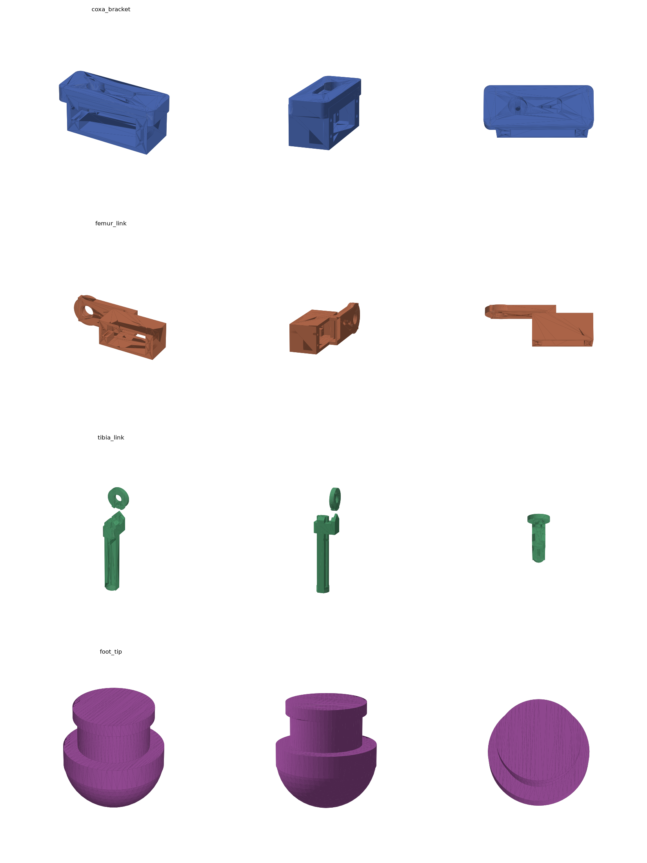
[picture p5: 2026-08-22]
docs/preview_leg_parts.png

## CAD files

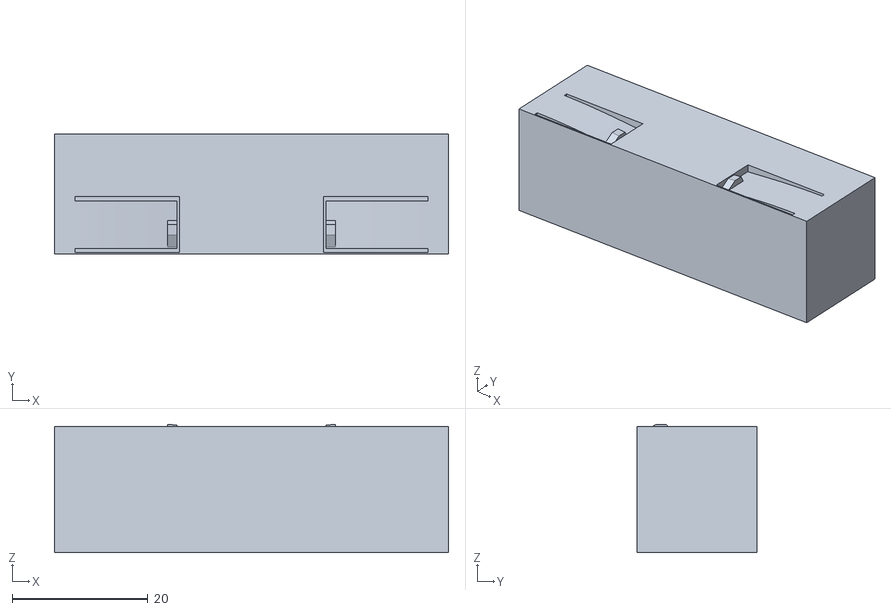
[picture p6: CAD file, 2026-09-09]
docs/audits/20260905-round2/cabin-electronics/candidate_latch_peg_lower_deflected.stl
58.0 x 17.6 x 18.9

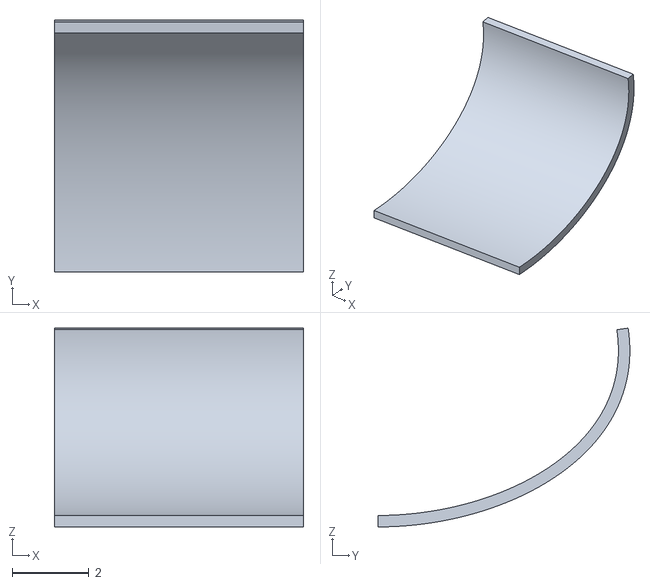
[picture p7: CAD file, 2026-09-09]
docs/audits/20260905-round2/camera-ov3660-candidate/OV3660_FPC_bent_candidate.stl
6.50 x 6.57 x 5.19

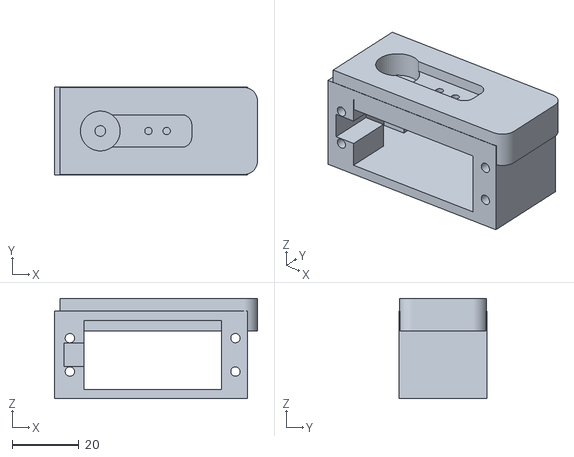
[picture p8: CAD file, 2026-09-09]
docs/audits/20260905-round2/coxa-before-pocket.stl
60.7 x 26.2 x 30.0

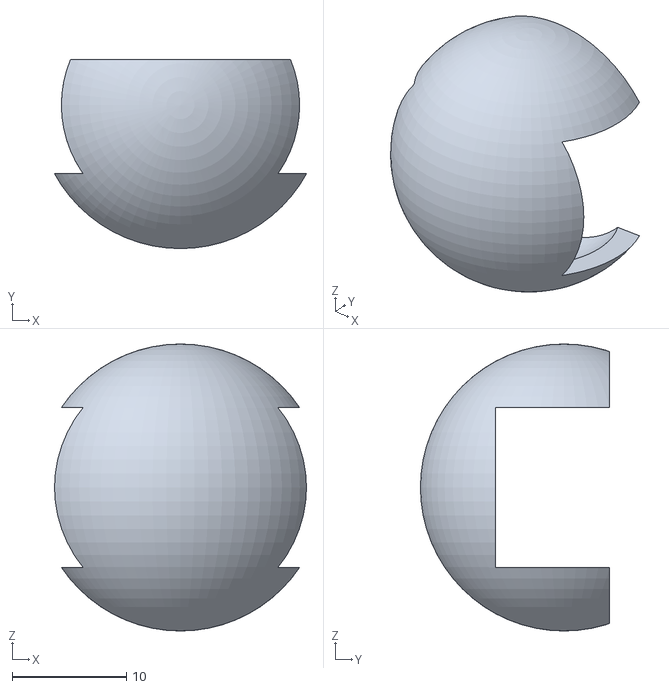
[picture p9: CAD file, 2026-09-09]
docs/audits/20260905-round2/elbow-cover-candidates/elbow_shell_shifted_y_minus13p8_candidate.stl
22.1 x 16.6 x 25.1

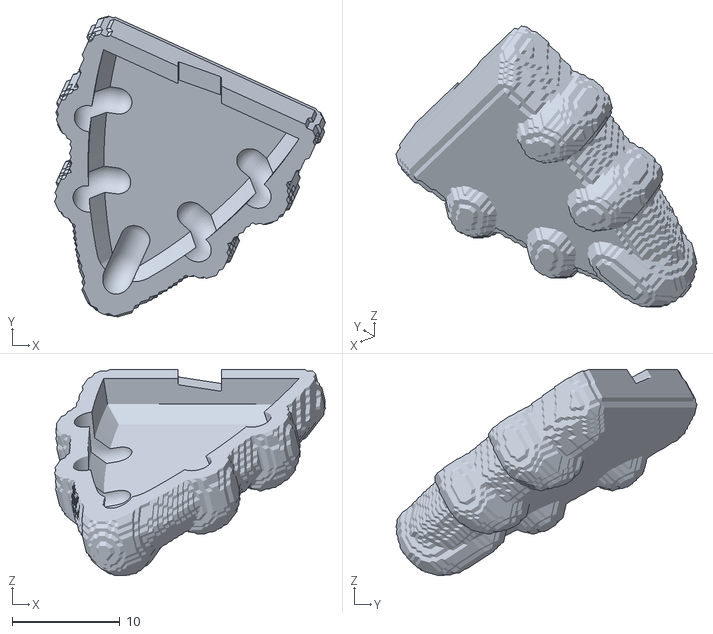
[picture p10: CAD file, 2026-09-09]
docs/audits/20260905-round2/foot-support-candidates/FR_0_shoe_fitted_candidate.stl
25.1 x 27.9 x 19.1

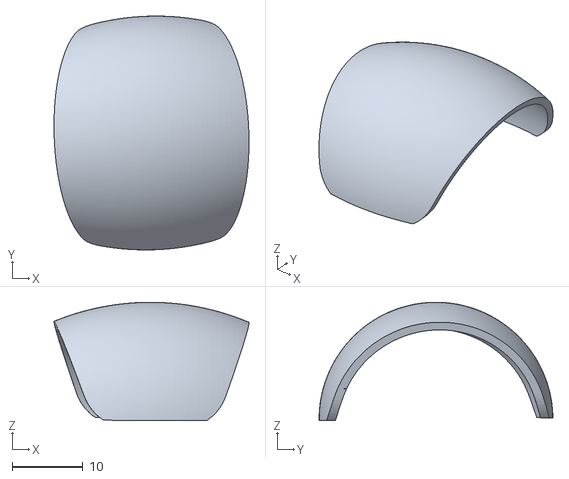
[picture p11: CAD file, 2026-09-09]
docs/audits/20260905-round2/guard-seat-candidates/femur_guard_link_unchanged.stl
27.5 x 32.9 x 16.7

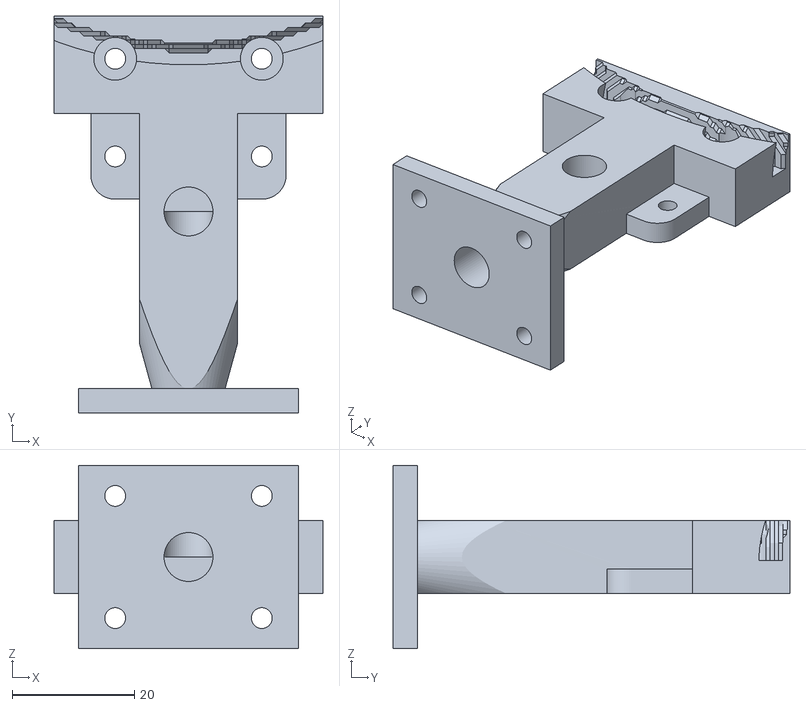
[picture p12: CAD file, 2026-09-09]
docs/audits/20260905-round2/neck-reinforcement-candidates/neck_frontwidth44.stl
44.0 x 65.0 x 30.0

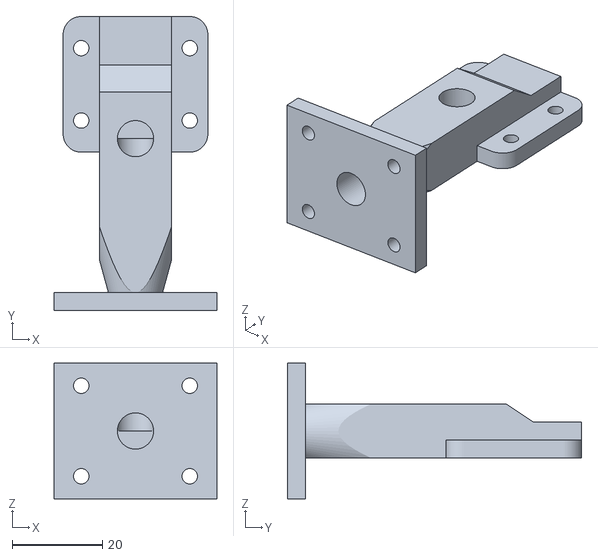
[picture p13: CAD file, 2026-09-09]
docs/audits/20260905-round2/neck-wire-candidates/neck_d8_exit-70.stl
36.0 x 65.0 x 30.0

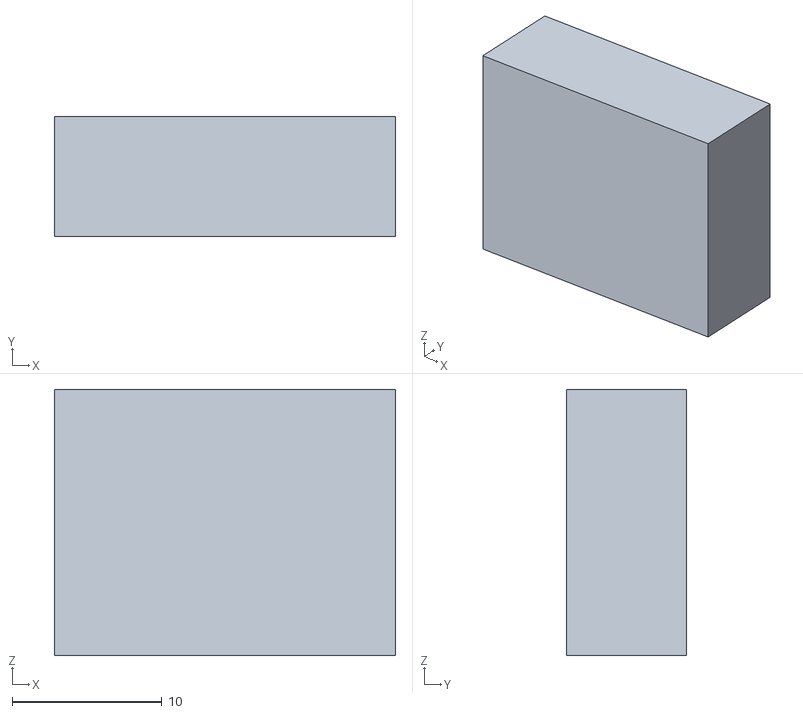
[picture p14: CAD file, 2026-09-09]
docs/audits/20260905-round2/primary-sources/xiao-step-measured/camera_removed_without_sd_envelope.stl
22.8 x 8.03 x 17.8

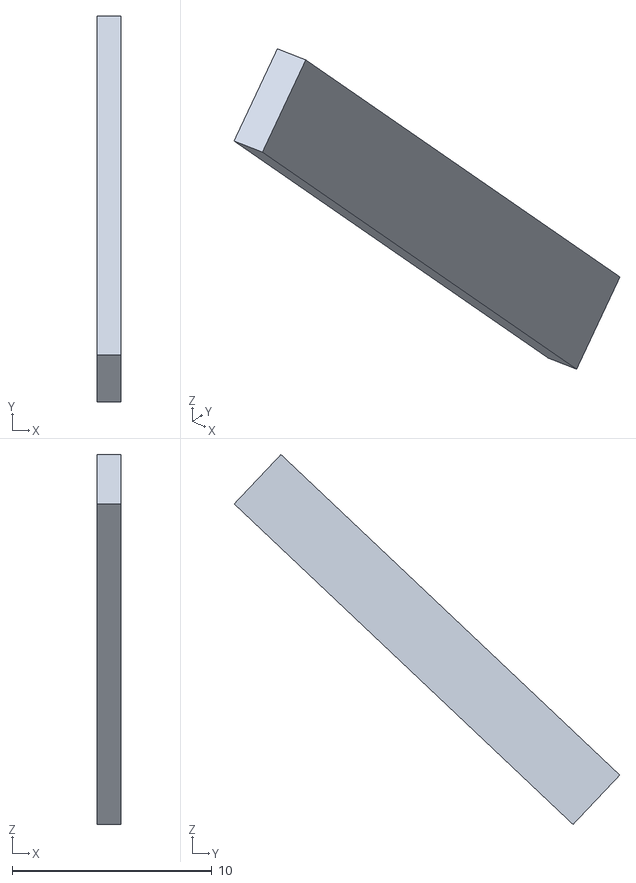
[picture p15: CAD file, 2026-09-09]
docs/audits/20260905-round2/xiao-retention-candidate/without_sd_xiao_tray_rib_left_candidate.stl
1.20 x 19.3 x 18.5

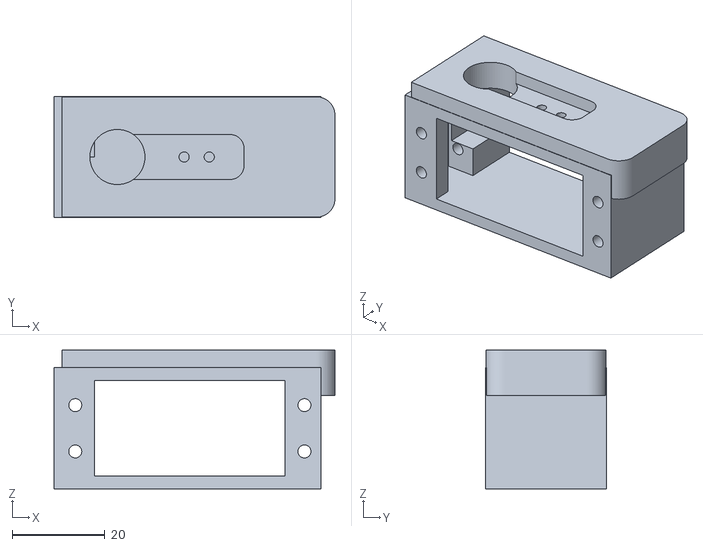
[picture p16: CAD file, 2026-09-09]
hardware/stl/coxa_bracket_m.stl
60.7 x 26.2 x 30.0

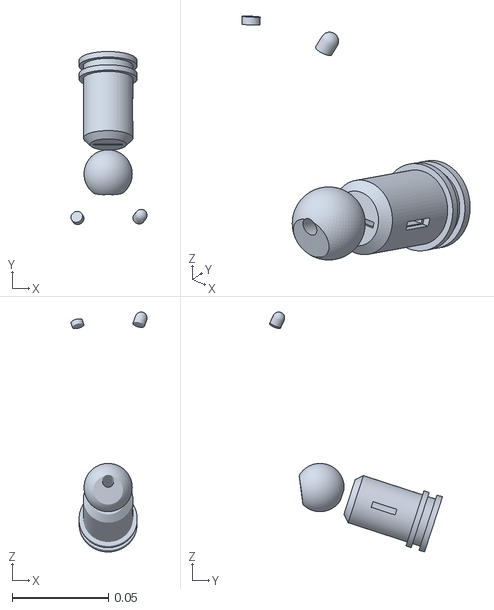
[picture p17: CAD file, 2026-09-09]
hardware/urdf-print-first/meshes/base_link__vis_grey.stl
0.0396 x 0.09 x 0.125

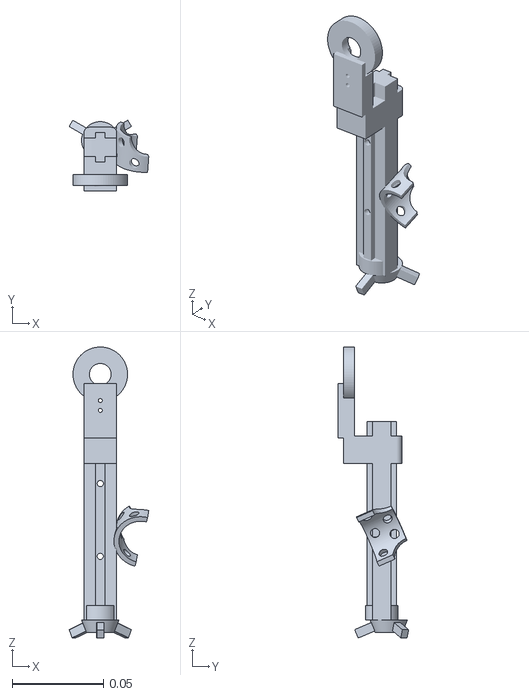
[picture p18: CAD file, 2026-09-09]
hardware/urdf/meshes/leg_fr_tibia__vis_grey.stl
0.0438 x 0.0388 x 0.16

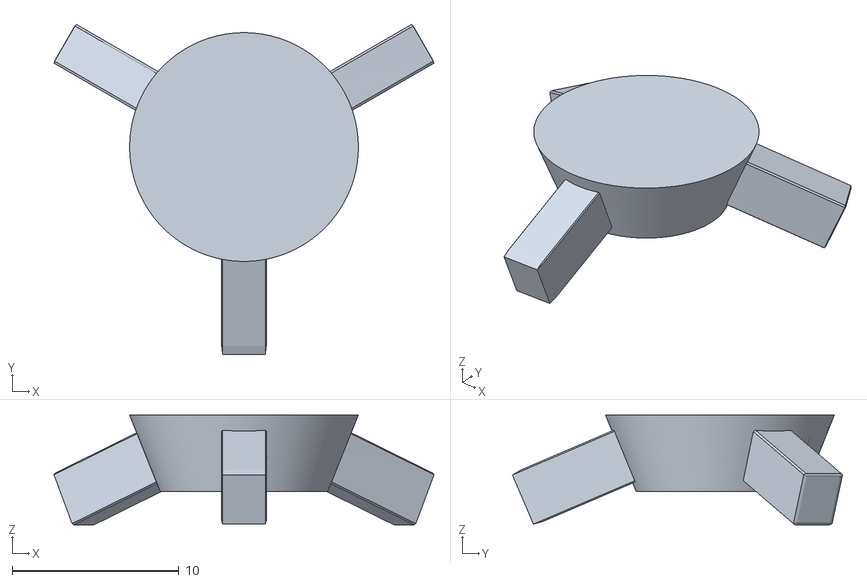
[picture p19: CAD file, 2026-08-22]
model/Leg_Foot_Grey_x4_Repaired.stl
22.8 x 19.8 x 6.57

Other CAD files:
outputs/print-first-20260905/body/pf_electronics_shelf_0.stl
outputs/print-first-20260905/feet/shin_shell_retained_m_foot_frame.stl
outputs/print-first-20260905/ld220-adapter-freeze2-final/ld220_cap.stl
outputs/print-first-20260905/legs/pf_ld220_coxa_cap_m.stl
TACHIKOMA_Phase0_PETG.3mf
docs/audits/20260905-round2/Shin_Guard_internal_seat_candidate.stl
docs/audits/20260905-round2/Thigh_Guard_internal_seat_candidate.stl
docs/audits/20260905-round2/cabin-electronics/candidate_cabin_back_crossover.stl
docs/audits/20260905-round2/cabin-electronics/candidate_cabin_back_with_latches.stl
docs/audits/20260905-round2/cabin-electronics/candidate_cabin_eye_half_depth7p39.stl
docs/audits/20260905-round2/cabin-electronics/candidate_cabin_front_pockets.stl
docs/audits/20260905-round2/cabin-electronics/candidate_cabin_front_with_wire_route.stl
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

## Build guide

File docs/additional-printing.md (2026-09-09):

# 追加印刷一覧（2026-09-06）

**現行の印刷優先構成は手持ちPLA＋TPU95Aです。PETGの追加購入は0とし、旧PETGのSTL／3MFは履歴として保持して現行必要数・今印刷可数へ集計しません。** 手持ちPLA／TPU95Aの銘柄・残量・良品数は未確認であり、追加購入0は着手方針を示す値です。

**旧台帳に基づく追加印刷の実数と現物の良品数は、まだ確定していません。** 現行print-firstの設計必要数は後段の三層表に分けて **56個**と記録しますが、今印刷可数は0です。印刷済みの根拠は主に 2026-08-31 の記録を 9/3 に計画へ転記したものです。9/4 の版差追記と 9/5 の GitHub 本文・コメントを確認しましたが、その後の実物の良品数を確定する記録はありません。以下の旧数量は現物確認済み在庫ではありません。

現 STL 99 件（加工品 41＋原型 58）と現 3MF 27 件を突合しました。部品ごとの SHA-256、詳細な向き・支持、旧記録、3MF 内の部品別比較値は [機械可読の全台帳](additional-printing.json) に保存しています。JSONの `summary.assembly_pieces=139` は旧全体キット台帳の履歴値で、`assembly_pieces_is_current_print_first_required=false` として現行必要数から除外しています。現行print-firstの正本は `current_print_first_required` が示す `docs/print-first-manifest.json#/production_quantity_layers/machine_design_required/total` で、正本SHA-256は `4763be639a3fce4d3dbd25075c3f7d3baf12c8308e1b29ff2b993eef508acd1a` です。正本から現行値56個、初回31個、残り25個、条件付き新規脛殻込み最大60個を参照し、現在の候補値は56個・今印刷可数0を維持します。PETG の部品21行とプレート11行には `current_print_first_required=false` と除外理由を付け、旧材料の履歴を消さずに現行集計から除外しています。本書は印刷順序の整理であり、印刷送信や現物加工は行っていません。

### 現行print-firstの個数の層

機構freeze2前の生成物を最終品として扱わず、設計必要数と今印刷可数を分けます。現行assemblyから算出した**量産未解放の設計必要数**は **body16＋legs20＋TPU靴4＋PLAスペーサー16＝56個**です。body16には頭殻の印刷逃がし1個と中央眼の印刷逃がし1個を追加置換として含めています。機構freeze2、足の厳密検査、実物適合、材料残量のゲートをすべて通過するまで、今印刷可数は **0個**です。

材料節約の初回内数は **31個**（body16＋各ユニーク脚STL1のlegs10＋TPU靴1＋スペーサー4）とし、適合後の残りは **25個**（legs10＋TPU靴3＋スペーサー12）です。これは設計必要数56の内数で、今印刷可数0を変更するものではありません。旧レビュー値54／初回29／最大58は比較値として保持します。

印刷の解放単位はA/B/Cに分けて扱います。Aは**初回全体仮組み31個**（全体仮組み用body16＋左右/前後の固有脚部品10＋1脚分足裏5）で、その内側の実物適合の最小対象が1靴・1脚です。BはAの合格後に進める残り25個です。Cは既存脛殻4個を加工できない場合だけ選ぶ新規4個で、設計上限は60個です。A＋B=56個で設計必要数56個に一致し、CはA/Bへ加えません。現在の `currently_printable_quantity=0` はA・B・Cの印刷解放が未確定という意味で、Aの試作を印刷済み・許可済みとは表しません。freeze2後はAの結果、Bの解放条件、Cの採否を別々に記録します。

| 解放単位 | 数量 | 解放条件 | 設計必要数との関係 |
|---|---:|---|---|
| A 初回全体仮組み | 31（body16＋固有脚部品10＋足裏5） | freeze2、足の厳密検査、材料・現物確認の結果を確認してから先行判定。実物適合の最小対象は1靴・1脚 | 初回内数の全量 |
| B A合格後の残数 | 25 | Aの実物適合・電装・最終CAD/組立・実C++物理試験が合格 | 設計必要数56の残り |
| C 条件付き新規脛殻 | 4 | 既存脛殻4個の局所加工・再使用が不成立の場合だけ | 設計上限60。Bへ加算しない |

| 層 | 設計必要数 | 初回内数 | 適合後残数 | 今印刷可数 | 扱い |
|---|---:|---:|---:|---:|---|
| 設計必要数（量産未解放） | **56** | **31** | **25** | 0 | body16（頭殻逃がし1・中央眼逃がし1・yaw蓋を含む）＋legs20＋TPU靴4＋PLAスペーサー16。最終freeze2後に再生成・再検査 |
| 条件付き新規脛殻 | 4 | — | — | 0 | 既存脛殻4個を加工できない場合だけ。設計上限は60個。既存加工と新規印刷を合計しない |
| 非本番LD適合治具 | `ld220_cradle` / `ld220_cap` / `ld220_horn_adapter` 各1 | — | — | 0 | 設計必要数56（または条件付き上限60）へ加算しない。一体化済みケージ・蓋・ホーン変換板も二重計上しない |

現行bodyの追加置換は、頭殻 `pf_head_top_clearanced` 1個（`Head_Top_Eyecut#single` の逃がし）と中央眼 `pf_eye_pod_camera_clearanced` 1個（`eye_pod_camera` の逃がし）です。`Mouth_Peg_Grey` は既存の原型参照として保管し、現行56個の設計必要数へ混ぜず、追加印刷を自動計上しません。

LD治具は実物寸法の確認に使う任意試験具です。推奨材料は手持ちPLA、基準面をベッドへ置く候補向きで、cradleは挿入口を上、capは皿穴側を上、horn_adapterはホーン受け面を上にします。0.20 mmは候補値で、壁数・充填率はA.massとスライサーで確定します。確認後も廃棄せず保管します。

### 少量試作の順序と合否

`currently_printable_quantity=0` のまま、実測に必要な最小試作だけを順に判定します。LD保持が不要と確認できた場合は治具を省略し、印刷済み品を増やしません。

1. **LD適合治具（必要時のみ）**: `ld220_cradle`、`ld220_cap`、`ld220_horn_adapter`を各1個。ケース外形・取付軸・ホーン径/PCD・ねじ・工具進入を実物で照合し、保持でき、干渉せず、無理な押し込みなしに取り外せること。3種とも非本番で、候補値の実測前採用はNo-Goです。
2. **TPU靴1個**: 1脚へ取り付け、四隅の接地、保持/引抜き、足裏の滑り、低速可動、工具・配線の進入を確認します。静荷重を段階的に加えて白化・裂け・永久変形・接着剥離がなく、硬いトゥが先行接地しないことを合否にします。接触力・材料強度・連続歩行は別ゲートで、合格を全4個の解放へ拡張しません。
3. **隠し補強1個（候補形状を確定できた場合のみ）**: 既存部品の内側へ仮合わせし、外観面を変えず、支持面の全周接触、ねじ/接着面、工具・配線経路、静荷重時のたわみと脱落を確認します。候補未確定の間は数量0・量産未解放とし、首補強候補11種を同時印刷しません。

各段階の合否は、使用STLのSHA、材料/積層、対象個体、寸法、荷重、変形、写真/動画を記録してから次段へ進めます。ホスト検査やnative traceのPASSだけで実機完成とは判定しません。

## 過去台帳の集計（現行56の集計には使わない）

| 区分 | 数 | 意味 |
|---|---:|---|
| 旧全体キット台帳の機体 1 台分 | 139 個 | 加工品 59＋原型 80。現行print-firstの必要数ではなく、組立成立の認定でもない。設計修正で増減し得る |
| 元キットの予備 Peg | 2 個 | 機体には使わない。前項に含めない |
| 旧全数計画に相当する総数 | 141 個 | 139＋予備 2。追加印刷数ではない |
| 任意の Stand | 最大 1 個 | 治具として採用するときだけ。141 に含めない |
| 今回形状を変えた STL | 10 ファイル・12 個分 | coxa 4、肩 2、前腕 2、Cannon 1、Neck 1、chassis 1、HeadBottom 1。旧未印刷分と重複する |
| 取付座標だけ変わった肘殻 | 2 ファイル・2 個分 | 今回の変更だけを理由とする再印刷は 0 |
| 手持ちを差し引いた追加数 | **未確定** | 旧記録から一律に差し引かない。設計採用・良品数・版の確認が必要 |

**「旧未印刷分＋今回変更の 12 個」と足し算しないでください。** 例えば肩・前腕は元々未印刷と記録されており、変更品として再び数えると重複します。逆に HeadBottom は旧品から材料を戻す変更があるため、削れば必ず流用できるとも言えません。旧品は保管し、[P-05](https://github.com/hapx2yuki/Tachikoma/issues/15) で部品ごとに判断します。

腕 Guard は旧表の Left 1＋Right 1 と、現モデルの Right 標準 1＋鏡像 1 が不一致です。上の合計はどちらも 2 個ですが、**採用形状は確定していません**。本書の Left 0／Right 2 は現モデルを説明する値で、意匠の左右統一を指示するものではありません。

## 先に進められる作業

1. [P-02](https://github.com/hapx2yuki/Tachikoma/issues/12) で「STL 名・標準/鏡像・良品数・印刷日・内側写真・旧版差」を記録する。プレートから部品が削除されていても、印刷成功の証拠にはしない。
2. 不足確認後、既知の形状変更・実交差がない Head_Dome、Head_Plug、小 RedLight は部品単位の仮合わせ試作を分離できる。灰/黒/赤プレート一式の再印刷にはしない。
3. 骨格は [P-03](https://github.com/hapx2yuki/Tachikoma/issues/13)→[P-04](https://github.com/hapx2yuki/Tachikoma/issues/14)→[P-05](https://github.com/hapx2yuki/Tachikoma/issues/15) の対象部品確認後、[PR-04](https://github.com/hapx2yuki/Tachikoma/issues/22) で標準 tibia 1 個。[L-02](https://github.com/hapx2yuki/Tachikoma/issues/37) 合格後に [PR-11](https://github.com/hapx2yuki/Tachikoma/issues/86) で標準 1＋鏡像 2 の不足分。
4. [PR-06](https://github.com/hapx2yuki/Tachikoma/issues/24) の設計必要数全量の印刷完了を待たず、腕・目・音声などの確定済み部品を別名プレートで個別に引き渡す。プリンタは 1 台なので送信は直列、実測・棚卸し・設計確認は並行してよい。

旧プレート名に付いている重量や所要時間は、今回の追加ジョブの見積りに流用しません。対象部品・現形状・向き・支持・充填率を確定してから、スライサーで必要 g と時間を求めます。フィラメント記録上の量は現在の残量ではありません。

層 0.2mm／ノズル 0.4mm が骨格の基準で、mic の指定は層 0.12mm。表の材質・壁・充填率は製造設定であり強度保証ではありません。原型の Toe・Finger は現3MFに合わせ壁3/15%、Peg は壁2/15%を保ち、全て壁2/8%へ弱めません。PETG の荷重試験は [RV-07](https://github.com/hapx2yuki/Tachikoma/issues/88)、床支持は [RV-06](https://github.com/hapx2yuki/Tachikoma/issues/87) を別々に判定します。金属 M3 ねじ、ナット、サーボ、基板などは [追加購入一覧](additional-purchases.md) の対象です。元キットの装飾 Head_Screw は PLA 部品なので本書に含めています。

表の「確認先」は、その Issue にある該当部品の設計・試験条件を示します。全ての Issue を丸ごと Close するまで一切試作できない、という依存ではありません。設計確認→1 個の試作→受入試験→残数という順序は、各行と最新の作業計画で管理します。

各表の追加範囲 0〜N は「現設計を維持するなら」という条件付きです。上限まで刷る指示ではありません。**hardware/stl は 100% で読み込み、model は 150% にします。既存 3MF 内で既に 150% の部品を再び拡大しないでください。**

今回の印刷優先候補（TPU靴、段付きスペーサー、青殻の既存加工/新規印刷の択一、開放電装棚、カメラ小物）は、数量とハッシュを [印刷優先マニフェスト](print-first-manifest.md) / [JSON](print-first-manifest.json) で別管理する。下記の過去候補行を足し合わせて新候補の追加数を作らない。試作1脚分は設計必要数の内数で、青殻4個の二案も同時に数えない。現行候補の材料は手持ちPLA＋TPU95Aの範囲で扱い、旧PETG行を候補数へ混ぜない。

## 脚の骨格・電池保持

| 部品 ID・STL | 必要数／標準・鏡像 | 材質・設定 | 旧印刷記録 | 追加・試験順序 | 先行確認／印刷 Issue | 現 3MF |
|---|---|---|---|---|---|---|
| `HW-battery_cradle`<br>[battery_cradle.stl](../hardware/stl/battery_cradle.stl) | 1<br>共通/標準 | PETG / 壁3, 20% | 1 個（旧記録）。Walk_1。反りと電池保持を確認。 | 未確定（現設計なら 0〜1）。旧 1 個を電池寸法・保持で確認。適合すれば追加 0、不足/不適合時だけ 1 個。 | [P-02](https://github.com/hapx2yuki/Tachikoma/issues/12) / [P-01](https://github.com/hapx2yuki/Tachikoma/issues/11)<br>印刷: [PR-09](https://github.com/hapx2yuki/Tachikoma/issues/27) | [PL-04](#pl-04) ×1 / [PL-07](#pl-07) ×1（同居品に不一致） |
| `HW-coxa_bracket`<br>[coxa_bracket.stl](../hardware/stl/coxa_bracket.stl)<br>**今回の形状変更**。天板の後方張出し短縮＋埋め戻されていたサーボケース/タブ/線の空間を復旧。旧 φ2.0→2.2 の穴加工だけでは現形状にならない。 | 2<br>標準 FL/RR | PETG / 壁4, 40% | 2 個（旧記録）。Walk_2、8/27。旧下穴 φ2.0。今回の天板・ケース空間の変更も必要。 | 未確定（現設計なら 0〜2）。FL 標準の不足分 1 個を先行。L-02 合格後に標準の残り 1＋鏡像 2（現物良品を差引く）。 | [P-02](https://github.com/hapx2yuki/Tachikoma/issues/12) / [P-03](https://github.com/hapx2yuki/Tachikoma/issues/13) / [P-04](https://github.com/hapx2yuki/Tachikoma/issues/14) / [P-05](https://github.com/hapx2yuki/Tachikoma/issues/15)<br>印刷: [PR-09](https://github.com/hapx2yuki/Tachikoma/issues/27) | [PL-05](#pl-05) ×2 **不一致** / [PL-08](#pl-08) ×2 **不一致** |
| `HW-coxa_bracket_m`<br>[coxa_bracket_m.stl](../hardware/stl/coxa_bracket_m.stl)<br>**今回の形状変更**。標準版と同じ内部修正の鏡像。既印刷 2 個の可否を別々に判定する。 | 2<br>鏡像済み STL FR/RL | PETG / 壁4, 40% | 2 個（旧記録）。Walk_2、8/27。旧下穴 φ2.0。今回の天板・ケース空間の変更も必要。 | 未確定（現設計なら 0〜2）。標準側 L-02 合格後に鏡像 1 個で向きを確認→鏡像の不足残数。 | [P-02](https://github.com/hapx2yuki/Tachikoma/issues/12) / [P-03](https://github.com/hapx2yuki/Tachikoma/issues/13) / [P-04](https://github.com/hapx2yuki/Tachikoma/issues/14) / [P-05](https://github.com/hapx2yuki/Tachikoma/issues/15)<br>印刷: [PR-09](https://github.com/hapx2yuki/Tachikoma/issues/27) | [PL-05](#pl-05) ×2 **不一致** / [PL-08](#pl-08) ×2 **不一致** |
| `HW-femur_link`<br>[femur_link.stl](../hardware/stl/femur_link.stl) | 2<br>標準 FL/RR | PETG / 壁4, 40% | 2 個（旧記録）。Walk_2、8/27。旧下穴 φ2.0 と現 φ2.2 の差、ホーン寸法を確認。 | 未確定（現設計なら 0〜2）。FL 標準の不足分 1 個を先行。L-02 合格後に標準の残り 1＋鏡像 2（現物良品を差引く）。 | [P-02](https://github.com/hapx2yuki/Tachikoma/issues/12) / [P-03](https://github.com/hapx2yuki/Tachikoma/issues/13) / [P-04](https://github.com/hapx2yuki/Tachikoma/issues/14) / [P-05](https://github.com/hapx2yuki/Tachikoma/issues/15)<br>印刷: [PR-09](https://github.com/hapx2yuki/Tachikoma/issues/27) | [PL-01](#pl-01) ×1 **不一致** / [PL-04](#pl-04) ×2 / [PL-08](#pl-08) ×2（同居品に不一致） |
| `HW-femur_link_m`<br>[femur_link_m.stl](../hardware/stl/femur_link_m.stl) | 2<br>鏡像済み STL FR/RL | PETG / 壁4, 40% | 2 個（旧記録）。Walk_2、8/27。旧下穴 φ2.0 と現 φ2.2 の差、ホーン寸法を確認。 | 未確定（現設計なら 0〜2）。標準側 L-02 合格後に鏡像 1 個で向きを確認→鏡像の不足残数。 | [P-02](https://github.com/hapx2yuki/Tachikoma/issues/12) / [P-03](https://github.com/hapx2yuki/Tachikoma/issues/13) / [P-04](https://github.com/hapx2yuki/Tachikoma/issues/14) / [P-05](https://github.com/hapx2yuki/Tachikoma/issues/15)<br>印刷: [PR-09](https://github.com/hapx2yuki/Tachikoma/issues/27) | [PL-04](#pl-04) ×2 / [PL-08](#pl-08) ×2（同居品に不一致） |
| `HW-tibia_link`<br>[tibia_link.stl](../hardware/stl/tibia_link.stl) | 2<br>標準 FL/RR | PETG / 壁4, 40% | 0 個（旧記録）。旧計画の未印刷群。以後の現物数は未確認。 | 未確定（現設計なら 0〜2）。PR-04 で標準 1 個→L-02→PR-11 で標準残り 1 個。 | [P-02](https://github.com/hapx2yuki/Tachikoma/issues/12) / [P-03](https://github.com/hapx2yuki/Tachikoma/issues/13) / [P-04](https://github.com/hapx2yuki/Tachikoma/issues/14) / [P-05](https://github.com/hapx2yuki/Tachikoma/issues/15) / [RV-07](https://github.com/hapx2yuki/Tachikoma/issues/88)<br>印刷: [PR-04](https://github.com/hapx2yuki/Tachikoma/issues/22) / [PR-11](https://github.com/hapx2yuki/Tachikoma/issues/86) | [PL-01](#pl-01) ×1 **不一致** / [PL-03](#pl-03) ×2 / [PL-09](#pl-09) ×2 |
| `HW-tibia_link_m`<br>[tibia_link_m.stl](../hardware/stl/tibia_link_m.stl) | 2<br>鏡像済み STL FR/RL | PETG / 壁4, 40% | 0 個（旧記録）。旧計画の未印刷群。以後の現物数は未確認。 | 未確定（現設計なら 0〜2）。標準 1 個の L-02 合格後、PR-11 で鏡像 1 個の適合確認→残り 1 個。 | [P-02](https://github.com/hapx2yuki/Tachikoma/issues/12) / [P-03](https://github.com/hapx2yuki/Tachikoma/issues/13) / [P-04](https://github.com/hapx2yuki/Tachikoma/issues/14) / [P-05](https://github.com/hapx2yuki/Tachikoma/issues/15) / [RV-07](https://github.com/hapx2yuki/Tachikoma/issues/88)<br>印刷: [PR-11](https://github.com/hapx2yuki/Tachikoma/issues/86) | [PL-03](#pl-03) ×2 / [PL-09](#pl-09) ×2 |

## 足・脚カバー・トゥ

足 1 個のソケット確認は、装飾なしの片脚ベンチとして分離できます。これは現 foot_pad による TPU 支持の合格ではありません。thigh_cap／Guard の保留を理由に、裸脚の限定試験まで一括で停止する必要はありません。

| 部品 ID・STL | 必要数／標準・鏡像 | 材質・設定 | 旧印刷記録 | 追加・試験順序 | 先行確認／印刷 Issue | 現 3MF |
|---|---|---|---|---|---|---|
| `HW-foot_pad`<br>[foot_pad.stl](../hardware/stl/foot_pad.stl) | 4<br>共通/標準 | TPU 95A / 壁3, 30% | 4 個（旧記録）。TPU 4 個という旧記録。現 foot_pad.3mf は 1 個だけ。 | 未確定（現設計なら 0〜4）。旧 TPU 4 個を保管。現位置は TPU 支持不成立で同形の追加を止める。採用形状を確定して 1 脚分→荷重/滑り/接着試験→残数。 | [P-02](https://github.com/hapx2yuki/Tachikoma/issues/12) / [RV-06](https://github.com/hapx2yuki/Tachikoma/issues/87)<br>印刷: [RV-06](https://github.com/hapx2yuki/Tachikoma/issues/87) | [PL-26](#pl-26) ×1 |
| `HW-leg_foot_bored`<br>[leg_foot_bored.stl](../hardware/stl/leg_foot_bored.stl) | 4<br>共通/標準 | PLA グレー / 壁3, 20% | 2 個（旧記録）。旧 rev の疑い。適合すれば残り 2 個、使えなければ最大 4 個だが、現棚卸しと RV-06 が先。 | 未確定（現設計なら 0〜4）。L-01 の足ソケット/保持だけを試す裸脚ベンチなら、P-03/P-04 後に不足 1 個を分離。床の TPU 支持合格とはしない。残りは RV-06 確定後。 | [P-02](https://github.com/hapx2yuki/Tachikoma/issues/12) / [RV-06](https://github.com/hapx2yuki/Tachikoma/issues/87)<br>裸脚の限定試作: [P-02](https://github.com/hapx2yuki/Tachikoma/issues/12) / [P-03](https://github.com/hapx2yuki/Tachikoma/issues/13) / [P-04](https://github.com/hapx2yuki/Tachikoma/issues/14) / [P-05](https://github.com/hapx2yuki/Tachikoma/issues/15)<br>印刷: [PR-05](https://github.com/hapx2yuki/Tachikoma/issues/23) | [PL-17](#pl-17) ×4（同居品に不一致） / [PL-27](#pl-27) ×1 |
| `HW-shin_shell`<br>[shin_shell.stl](../hardware/stl/shin_shell.stl) | 2<br>標準 FL/RR | PLA 青 / 壁2, 6% | 2 個（旧記録）。Blue_1、8/20。現 3MF は標準 1 個だけで、印刷履歴とは別。 | 未確定（現設計なら 0〜2）。不足かつ使用設計が確定した場合に 1 個→嵌合確認→必要残数。既存良品があれば試験にも流用。 | [P-02](https://github.com/hapx2yuki/Tachikoma/issues/12) / [RV-16](https://github.com/hapx2yuki/Tachikoma/issues/97)<br>印刷: [PR-09](https://github.com/hapx2yuki/Tachikoma/issues/27) | [PL-12](#pl-12) ×1 |
| `HW-shin_shell_m`<br>[shin_shell_m.stl](../hardware/stl/shin_shell_m.stl) | 2<br>鏡像済み STL FR/RL | PLA 青 / 壁2, 6% | 2 個（旧記録）。Blue_1、8/20。現 Blue_1 には鏡像がない。 | 未確定（現設計なら 0〜2）。不足かつ使用設計が確定した場合に 1 個→嵌合確認→必要残数。既存良品があれば試験にも流用。 | [P-02](https://github.com/hapx2yuki/Tachikoma/issues/12) / [RV-16](https://github.com/hapx2yuki/Tachikoma/issues/97)<br>印刷: [PR-09](https://github.com/hapx2yuki/Tachikoma/issues/27) | **未収録**。現 STL を別名プレートへ。 |
| `HW-thigh_cap`<br>[thigh_cap.stl](../hardware/stl/thigh_cap.stl) | 4<br>共通/標準 | PLA グレー / 壁2, 6% | 0 個（旧記録）。旧計画の未印刷群。以後の現物数は未確認。 | 未確定（現設計なら 0〜4）。不足かつ使用設計が確定した場合に 1 個→嵌合確認→必要残数。既存良品があれば試験にも流用。 | [P-02](https://github.com/hapx2yuki/Tachikoma/issues/12) / [RV-16](https://github.com/hapx2yuki/Tachikoma/issues/97) / [RV-14](https://github.com/hapx2yuki/Tachikoma/issues/95)<br>印刷: [PR-05](https://github.com/hapx2yuki/Tachikoma/issues/23) | [PL-17](#pl-17) ×4（同居品に不一致） |
| `KIT-Leg_Shin_Guard_Grey_x4`<br>[Leg_Shin_Guard_Grey_x4.stl](../model/Leg_Shin_Guard_Grey_x4.stl) | 4<br>共通/標準 | PLA グレー / 壁2, 8% | 0 個（旧記録）。旧計画の未印刷群。以後の現物数は未確認。 | 未確定（現設計なら 0〜4）。不足かつ使用設計が確定した場合に 1 個→嵌合確認→必要残数。既存良品があれば試験にも流用。 | [P-02](https://github.com/hapx2yuki/Tachikoma/issues/12) / [RV-16](https://github.com/hapx2yuki/Tachikoma/issues/97)<br>印刷: [PR-01](https://github.com/hapx2yuki/Tachikoma/issues/19) | [PL-18](#pl-18) ×4 |
| `KIT-Leg_Thigh_Guard_Blue_x4`<br>[Leg_Thigh_Guard_Blue_x4.stl](../model/Leg_Thigh_Guard_Blue_x4.stl) | 4<br>共通/標準 | PLA 青 / 壁2, 8% | 4 個（旧記録）。Blue_4。初回ブリム無し失敗の記録あり。良品 4 個が揃うか不明。 | 未確定（現設計なら 0〜4）。不足かつ使用設計が確定した場合に 1 個→嵌合確認→必要残数。既存良品があれば試験にも流用。 | [P-02](https://github.com/hapx2yuki/Tachikoma/issues/12) / [RV-16](https://github.com/hapx2yuki/Tachikoma/issues/97) / [RV-14](https://github.com/hapx2yuki/Tachikoma/issues/95)<br>印刷: [PR-09](https://github.com/hapx2yuki/Tachikoma/issues/27) | [PL-15](#pl-15) ×4 |
| `KIT-Leg_Toe_Black_x12`<br>[Leg_Toe_Black_x12.stl](../model/Leg_Toe_Black_x12.stl)<br>表示/検査の誤った 100% 行列を実物指定 150% へ訂正。既存 150% 印刷品のサイズを変える指示ではない。根元嵌合・TPU 支持は未成立。 | 12<br>共通/標準 | PLA 黒 / 壁3, 15% | 0 個（旧記録）。旧計画の未印刷群。以後の現物数は未確認。 | 未確定（現設計なら 0〜12）。150% 既印刷品は再拡大しない。根元嵌合と接地を確定後、1 脚 3 個で試験→他脚の不足分。 | [P-02](https://github.com/hapx2yuki/Tachikoma/issues/12) / [RV-06](https://github.com/hapx2yuki/Tachikoma/issues/87)<br>印刷: [PR-02](https://github.com/hapx2yuki/Tachikoma/issues/20) | [PL-11](#pl-11) ×12 |

## 腕・手・腕のカバー

肩・前腕の局所修正は本流へ反映済みです。現サーボを使った片腕試験と、頭部内で全ケースが収まるかの判定を分けます。旧肘殻は取付向きを直して検品し、形状不変のため自動的に刷り直しません。

| 部品 ID・STL | 必要数／標準・鏡像 | 材質・設定 | 旧印刷記録 | 追加・試験順序 | 先行確認／印刷 Issue | 現 3MF |
|---|---|---|---|---|---|---|
| `HW-arm_pod_lower`<br>[arm_pod_lower.stl](../hardware/stl/arm_pod_lower.stl) | 1<br>共通/標準 | PLA 青 / 壁2, 8% | 1 個（旧記録）。Blue_2 の旧記録。現 Blue_2 には未収録。 | 未確定（現設計なら 0〜1）。旧印刷各 1 個を先に確認。肩/上腕/肘の全ケースと干渉なく組めれば追加 0。 | [P-02](https://github.com/hapx2yuki/Tachikoma/issues/12) / [P-03](https://github.com/hapx2yuki/Tachikoma/issues/13) / [P-04](https://github.com/hapx2yuki/Tachikoma/issues/14) / [RV-10](https://github.com/hapx2yuki/Tachikoma/issues/91)<br>印刷: [PR-06](https://github.com/hapx2yuki/Tachikoma/issues/24) | **未収録**。現 STL を別名プレートへ。 |
| `HW-arm_pod_lower_L`<br>[arm_pod_lower_L.stl](../hardware/stl/arm_pod_lower_L.stl) | 1<br>鏡像済み STL 左腕 | PLA 青 / 壁2, 8% | 1 個（旧記録）。Blue_2 の旧記録。現 Blue_2 には未収録。 | 未確定（現設計なら 0〜1）。旧印刷各 1 個を先に確認。肩/上腕/肘の全ケースと干渉なく組めれば追加 0。 | [P-02](https://github.com/hapx2yuki/Tachikoma/issues/12) / [P-03](https://github.com/hapx2yuki/Tachikoma/issues/13) / [P-04](https://github.com/hapx2yuki/Tachikoma/issues/14) / [RV-10](https://github.com/hapx2yuki/Tachikoma/issues/91)<br>印刷: [PR-06](https://github.com/hapx2yuki/Tachikoma/issues/24) | **未収録**。現 STL を別名プレートへ。 |
| `HW-arm_pod_upper`<br>[arm_pod_upper.stl](../hardware/stl/arm_pod_upper.stl) | 1<br>共通/標準 | PLA 青 / 壁2, 8% | 1 個（旧記録）。Blue_2 の旧記録。現 Blue_2 には未収録。 | 未確定（現設計なら 0〜1）。旧印刷各 1 個を先に確認。肩/上腕/肘の全ケースと干渉なく組めれば追加 0。 | [P-02](https://github.com/hapx2yuki/Tachikoma/issues/12) / [P-03](https://github.com/hapx2yuki/Tachikoma/issues/13) / [P-04](https://github.com/hapx2yuki/Tachikoma/issues/14) / [RV-10](https://github.com/hapx2yuki/Tachikoma/issues/91)<br>印刷: [PR-06](https://github.com/hapx2yuki/Tachikoma/issues/24) | **未収録**。現 STL を別名プレートへ。 |
| `HW-arm_pod_upper_L`<br>[arm_pod_upper_L.stl](../hardware/stl/arm_pod_upper_L.stl) | 1<br>鏡像済み STL 左腕 | PLA 青 / 壁2, 8% | 1 個（旧記録）。Blue_2 の旧記録。現 Blue_2 には未収録。 | 未確定（現設計なら 0〜1）。旧印刷各 1 個を先に確認。肩/上腕/肘の全ケースと干渉なく組めれば追加 0。 | [P-02](https://github.com/hapx2yuki/Tachikoma/issues/12) / [P-03](https://github.com/hapx2yuki/Tachikoma/issues/13) / [P-04](https://github.com/hapx2yuki/Tachikoma/issues/14) / [RV-10](https://github.com/hapx2yuki/Tachikoma/issues/91)<br>印刷: [PR-06](https://github.com/hapx2yuki/Tachikoma/issues/24) | **未収録**。現 STL を別名プレートへ。 |
| `HW-claw_mount`<br>[claw_mount.stl](../hardware/stl/claw_mount.stl) | 1<br>共通/標準 | PETG / 壁4, 40% | 0 個（旧記録）。旧計画の未印刷群。以後の現物数は未確認。 | 未確定（現設計なら 0〜1）。RV-17 で手の接着座と差込経路を確定→片手分（爪 1・指 3・先端 3）→反対側。不明な重なりを削って吸収しない。 | [P-02](https://github.com/hapx2yuki/Tachikoma/issues/12) / [P-03](https://github.com/hapx2yuki/Tachikoma/issues/13) / [P-04](https://github.com/hapx2yuki/Tachikoma/issues/14) / [RV-17](https://github.com/hapx2yuki/Tachikoma/issues/98)<br>印刷: [PR-06](https://github.com/hapx2yuki/Tachikoma/issues/24) | [PL-02](#pl-02) ×1（同居品に不一致） / [PL-10](#pl-10) ×1（同居品に不一致） |
| `HW-claw_mount_L`<br>[claw_mount_L.stl](../hardware/stl/claw_mount_L.stl) | 1<br>鏡像済み STL 左腕 | PETG / 壁4, 40% | 1 個（旧記録）。先行分 1 個のみ明記。現在同名 3MF の 9 部品全てが印刷済みとはしない。 | 未確定（現設計なら 0〜1）。RV-17 で手の接着座と差込経路を確定→片手分（爪 1・指 3・先端 3）→反対側。不明な重なりを削って吸収しない。 | [P-02](https://github.com/hapx2yuki/Tachikoma/issues/12) / [P-03](https://github.com/hapx2yuki/Tachikoma/issues/13) / [P-04](https://github.com/hapx2yuki/Tachikoma/issues/14) / [RV-17](https://github.com/hapx2yuki/Tachikoma/issues/98)<br>印刷: [PR-06](https://github.com/hapx2yuki/Tachikoma/issues/24) | [PL-02](#pl-02) ×1（同居品に不一致） / [PL-10](#pl-10) ×1（同居品に不一致） / [PL-23](#pl-23) ×1（同居品に不一致） |
| `HW-elbow_shell`<br>[elbow_shell.stl](../hardware/stl/elbow_shell.stl)<br>**配置だけ変更・形状同一** | 1<br>共通/標準 | PLA グレー / 壁2, 15% | 1 個（旧記録）。elbow_shells。今回の STL 差は取付座標のみ。 | 未確定（現設計なら 0〜1）。既印刷の左右 1 個ずつを新しい取付向きで検品。形状同一なので再印刷を前提にしない。 | [P-02](https://github.com/hapx2yuki/Tachikoma/issues/12) / [P-03](https://github.com/hapx2yuki/Tachikoma/issues/13) / [P-04](https://github.com/hapx2yuki/Tachikoma/issues/14) / [RV-10](https://github.com/hapx2yuki/Tachikoma/issues/91)<br>印刷: [PR-06](https://github.com/hapx2yuki/Tachikoma/issues/24) | [PL-23](#pl-23) ×1（同居品に不一致） / [PL-24](#pl-24) ×1 |
| `HW-elbow_shell_L`<br>[elbow_shell_L.stl](../hardware/stl/elbow_shell_L.stl)<br>**配置だけ変更・形状同一** | 1<br>鏡像済み STL 左腕 | PLA グレー / 壁2, 15% | 1 個（旧記録）。elbow_shells。今回の STL 差は取付座標のみ。 | 未確定（現設計なら 0〜1）。既印刷の左右 1 個ずつを新しい取付向きで検品。形状同一なので再印刷を前提にしない。 | [P-02](https://github.com/hapx2yuki/Tachikoma/issues/12) / [P-03](https://github.com/hapx2yuki/Tachikoma/issues/13) / [P-04](https://github.com/hapx2yuki/Tachikoma/issues/14) / [RV-10](https://github.com/hapx2yuki/Tachikoma/issues/91)<br>印刷: [PR-06](https://github.com/hapx2yuki/Tachikoma/issues/24) | [PL-23](#pl-23) ×1（同居品に不一致） / [PL-24](#pl-24) ×1 |
| `HW-forearm`<br>[forearm.stl](../hardware/stl/forearm.stl)<br>**今回の形状変更**。上腕・肘殻との重なりを避ける内部形状へ修正。前腕長は維持。 | 1<br>共通/標準 | PETG / 壁4, 40% | 0 個（旧記録）。旧計画の未印刷群。以後の現物数は未確認。 | 未確定（現設計なら 0〜1）。A-01 用の右 1 個を現サーボと試験→A-02 の左 1 個。単体合格で RV-09 の本体内ケース干渉を解決済みとはしない。 | [P-02](https://github.com/hapx2yuki/Tachikoma/issues/12) / [P-03](https://github.com/hapx2yuki/Tachikoma/issues/13) / [P-04](https://github.com/hapx2yuki/Tachikoma/issues/14) / [RV-10](https://github.com/hapx2yuki/Tachikoma/issues/91)<br>印刷: [PR-06](https://github.com/hapx2yuki/Tachikoma/issues/24) | [PL-05](#pl-05) ×1 **不一致** / [PL-10](#pl-10) ×1 **不一致** / [PL-23](#pl-23) ×1 **不一致** |
| `HW-forearm_L`<br>[forearm_L.stl](../hardware/stl/forearm_L.stl)<br>**今回の形状変更**。前腕内部形状修正の左版。 | 1<br>鏡像済み STL 左腕 | PETG / 壁4, 40% | 0 個（旧記録）。旧計画の未印刷群。以後の現物数は未確認。 | 未確定（現設計なら 0〜1）。A-01 用の右 1 個を現サーボと試験→A-02 の左 1 個。単体合格で RV-09 の本体内ケース干渉を解決済みとはしない。 | [P-02](https://github.com/hapx2yuki/Tachikoma/issues/12) / [P-03](https://github.com/hapx2yuki/Tachikoma/issues/13) / [P-04](https://github.com/hapx2yuki/Tachikoma/issues/14) / [RV-10](https://github.com/hapx2yuki/Tachikoma/issues/91)<br>印刷: [PR-06](https://github.com/hapx2yuki/Tachikoma/issues/24) | [PL-05](#pl-05) ×1 **不一致** / [PL-10](#pl-10) ×1 **不一致** / [PL-23](#pl-23) ×1 **不一致** |
| `HW-shoulder_bracket`<br>[shoulder_bracket.stl](../hardware/stl/shoulder_bracket.stl)<br>**今回の形状変更**。上腕との回転干渉を内部逃げで解消。単体嵌合後、頭内の実ケース同士の配置問題は別に残る。 | 1<br>共通/標準 | PETG / 壁4, 40% | 0 個（旧記録）。旧計画の未印刷群。以後の現物数は未確認。 | 未確定（現設計なら 0〜1）。A-01 用の右 1 個を現サーボと試験→A-02 の左 1 個。単体合格で RV-09 の本体内ケース干渉を解決済みとはしない。 | [P-02](https://github.com/hapx2yuki/Tachikoma/issues/12) / [P-03](https://github.com/hapx2yuki/Tachikoma/issues/13) / [P-04](https://github.com/hapx2yuki/Tachikoma/issues/14) / [RV-10](https://github.com/hapx2yuki/Tachikoma/issues/91)<br>印刷: [PR-06](https://github.com/hapx2yuki/Tachikoma/issues/24) | [PL-05](#pl-05) ×1 **不一致** / [PL-23](#pl-23) ×1 **不一致** |
| `HW-shoulder_bracket_L`<br>[shoulder_bracket_L.stl](../hardware/stl/shoulder_bracket_L.stl)<br>**今回の形状変更**。肩ブラケット内部逃げの左版。標準と混用しない。 | 1<br>鏡像済み STL 左腕 | PETG / 壁4, 40% | 0 個（旧記録）。旧計画の未印刷群。以後の現物数は未確認。 | 未確定（現設計なら 0〜1）。A-01 用の右 1 個を現サーボと試験→A-02 の左 1 個。単体合格で RV-09 の本体内ケース干渉を解決済みとはしない。 | [P-02](https://github.com/hapx2yuki/Tachikoma/issues/12) / [P-03](https://github.com/hapx2yuki/Tachikoma/issues/13) / [P-04](https://github.com/hapx2yuki/Tachikoma/issues/14) / [RV-10](https://github.com/hapx2yuki/Tachikoma/issues/91)<br>印刷: [PR-06](https://github.com/hapx2yuki/Tachikoma/issues/24) | [PL-05](#pl-05) ×1 **不一致** / [PL-23](#pl-23) ×1 **不一致** |
| `HW-upper_arm`<br>[upper_arm.stl](../hardware/stl/upper_arm.stl) | 1<br>共通/標準 | PETG / 壁4, 40% | 0 個（旧記録）。旧計画の未印刷群。以後の現物数は未確認。 | 未確定（現設計なら 0〜1）。A-01 用の右 1 個を現サーボと試験→A-02 の左 1 個。単体合格で RV-09 の本体内ケース干渉を解決済みとはしない。 | [P-02](https://github.com/hapx2yuki/Tachikoma/issues/12) / [P-03](https://github.com/hapx2yuki/Tachikoma/issues/13) / [P-04](https://github.com/hapx2yuki/Tachikoma/issues/14) / [RV-10](https://github.com/hapx2yuki/Tachikoma/issues/91)<br>印刷: [PR-06](https://github.com/hapx2yuki/Tachikoma/issues/24) | [PL-05](#pl-05) ×1（同居品に不一致） / [PL-23](#pl-23) ×1（同居品に不一致） |
| `HW-upper_arm_L`<br>[upper_arm_L.stl](../hardware/stl/upper_arm_L.stl) | 1<br>鏡像済み STL 左腕 | PETG / 壁4, 40% | 0 個（旧記録）。旧計画の未印刷群。以後の現物数は未確認。 | 未確定（現設計なら 0〜1）。A-01 用の右 1 個を現サーボと試験→A-02 の左 1 個。単体合格で RV-09 の本体内ケース干渉を解決済みとはしない。 | [P-02](https://github.com/hapx2yuki/Tachikoma/issues/12) / [P-03](https://github.com/hapx2yuki/Tachikoma/issues/13) / [P-04](https://github.com/hapx2yuki/Tachikoma/issues/14) / [RV-10](https://github.com/hapx2yuki/Tachikoma/issues/91)<br>印刷: [PR-06](https://github.com/hapx2yuki/Tachikoma/issues/24) | [PL-05](#pl-05) ×1（同居品に不一致） / [PL-23](#pl-23) ×1（同居品に不一致） |
| `KIT-Arm_Left_Claw_Grey`<br>[Arm_Left_Claw_Grey.stl](../model/Arm_Left_Claw_Grey.stl) | 2<br>標準 1＋鏡像 1（左右腕） | PLA グレー / 壁2, 8% | 0 個（旧記録）。旧計画の未印刷群。以後の現物数は未確認。単発 leg_foot_bored.3mf に 1 個同居するが、印刷成功記録とはしない。 | 未確定（現設計なら 0〜2）。RV-17 で手の接着座と差込経路を確定→片手分（爪 1・指 3・先端 3）→反対側。不明な重なりを削って吸収しない。保存3MFは鏡像複製ではないため、左右同じ現物で適合するかも確認する。 | [P-02](https://github.com/hapx2yuki/Tachikoma/issues/12) / [RV-17](https://github.com/hapx2yuki/Tachikoma/issues/98)<br>印刷: [PR-01](https://github.com/hapx2yuki/Tachikoma/issues/19) | [PL-18](#pl-18) ×2 / [PL-27](#pl-27) ×1 |
| `KIT-Arm_Left_FingerTip_Grey_x3`<br>[Arm_Left_FingerTip_Grey_x3.stl](../model/Arm_Left_FingerTip_Grey_x3.stl) | 6<br>標準 3＋鏡像 3（左右腕） | PLA グレー / 壁2, 8% | 0 個（旧記録）。旧計画の未印刷群。以後の現物数は未確認。 | 未確定（現設計なら 0〜6）。RV-17 で手の接着座と差込経路を確定→片手分（爪 1・指 3・先端 3）→反対側。不明な重なりを削って吸収しない。保存3MFは鏡像複製ではないため、左右同じ現物で適合するかも確認する。 | [P-02](https://github.com/hapx2yuki/Tachikoma/issues/12) / [RV-17](https://github.com/hapx2yuki/Tachikoma/issues/98)<br>印刷: [PR-01](https://github.com/hapx2yuki/Tachikoma/issues/19) | [PL-18](#pl-18) ×6 |
| `KIT-Arm_Left_Finger_Black_x3`<br>[Arm_Left_Finger_Black_x3.stl](../model/Arm_Left_Finger_Black_x3.stl) | 6<br>標準 3＋鏡像 3（左右腕） | PLA 黒 / 壁3, 15% | 0 個（旧記録）。旧計画の未印刷群。以後の現物数は未確認。 | 未確定（現設計なら 0〜6）。RV-17 で手の接着座と差込経路を確定→片手分（爪 1・指 3・先端 3）→反対側。不明な重なりを削って吸収しない。保存3MFは鏡像複製ではないため、左右同じ現物で適合するかも確認する。 | [P-02](https://github.com/hapx2yuki/Tachikoma/issues/12) / [RV-17](https://github.com/hapx2yuki/Tachikoma/issues/98)<br>印刷: [PR-02](https://github.com/hapx2yuki/Tachikoma/issues/20) | [PL-11](#pl-11) ×6 |
| `KIT-Arm_Left_Guard_Grey`<br>[Arm_Left_Guard_Grey.stl](../model/Arm_Left_Guard_Grey.stl)<br>数量表と現実装の差。元 Left/Right の意匠を無断で統一する指示ではない。 | 0<br>旧表は左 1。現モデル採用なし（方針未確定） | PLA グレー / 壁2, 8% | 0 個（旧記録）。旧 Gray_2 の未印刷群。現実装との差があるため採用形状も未確定。 | 未確定。旧表 Left 1＋Right 1 と現モデル Right 標準 1＋鏡像 1 が不一致。どちらを使うか決めるまで追加しない。 | [P-02](https://github.com/hapx2yuki/Tachikoma/issues/12) / [RV-10](https://github.com/hapx2yuki/Tachikoma/issues/91) / [A-04](https://github.com/hapx2yuki/Tachikoma/issues/49)<br>印刷: [PR-01](https://github.com/hapx2yuki/Tachikoma/issues/19) | [PL-18](#pl-18) ×1 |
| `KIT-Arm_Right_Guard_Grey`<br>[Arm_Right_Guard_Grey.stl](../model/Arm_Right_Guard_Grey.stl)<br>数量表と現実装の差。元 Left/Right の意匠を無断で統一する指示ではない。 | 2<br>現モデルは標準 1＋鏡像 1（旧表は右 1） | PLA グレー / 壁2, 8% | 0 個（旧記録）。旧計画の未印刷群。以後の現物数は未確認。 | 未確定（現設計なら 0〜2）。旧表 Left 1＋Right 1 と現モデル Right 標準 1＋鏡像 1 が不一致。どちらを使うか決めるまで追加しない。 | [P-02](https://github.com/hapx2yuki/Tachikoma/issues/12) / [RV-10](https://github.com/hapx2yuki/Tachikoma/issues/91) / [A-04](https://github.com/hapx2yuki/Tachikoma/issues/49)<br>印刷: [PR-01](https://github.com/hapx2yuki/Tachikoma/issues/19) | [PL-18](#pl-18) ×1 |

## シャーシ・頭・目・カメラ・音声

| 部品 ID・STL | 必要数／標準・鏡像 | 材質・設定 | 旧印刷記録 | 追加・試験順序 | 先行確認／印刷 Issue | 現 3MF |
|---|---|---|---|---|---|---|
| `HW-Head_Bottom_Armcut`<br>[Head_Bottom_Armcut.stl](../hardware/stl/Head_Bottom_Armcut.stl)<br>**今回の形状変更**。過剰に切られた領域を復旧し体積が約 2294mm³ 増加。旧品を削るだけでは復元できない。新規/補強の可否は頭収納・支持を確定後に判断。 | 1<br>共通/標準 | PLA 青 / 壁2, 8% | 1 個（旧記録）。Blue_2、8/20。今回の過切削復旧前で材料が不足する可能性。 | 未確定（現設計なら 0〜1）。収納・頭の支持を確定後、現物の内部写真と版を確認。不足/不適合時だけ採用版 1 個。v2 の存在だけでは全体合格にならない。 | [P-02](https://github.com/hapx2yuki/Tachikoma/issues/12) / [RV-09](https://github.com/hapx2yuki/Tachikoma/issues/90) / [RV-13](https://github.com/hapx2yuki/Tachikoma/issues/94)<br>印刷: [PR-08](https://github.com/hapx2yuki/Tachikoma/issues/26) | [PL-13](#pl-13) ×1 **不一致** |
| `HW-Head_Top_Eyecut`<br>[Head_Top_Eyecut.stl](../hardware/stl/Head_Top_Eyecut.stl) | 1<br>共通/標準 | PLA 青 / 壁2, 8%※ | 1 個（旧記録）。Blue_1、8/20 の旧版の可能性。8/22 以降の中空 v2 の有無は未確認。 | 未確定（現設計なら 0〜1）。収納・頭の支持を確定後、現物の内部写真と版を確認。不足/不適合時だけ採用版 1 個。v2 の存在だけでは全体合格にならない。 | [P-02](https://github.com/hapx2yuki/Tachikoma/issues/12) / [RV-09](https://github.com/hapx2yuki/Tachikoma/issues/90) / [RV-13](https://github.com/hapx2yuki/Tachikoma/issues/94)<br>印刷: [PR-08](https://github.com/hapx2yuki/Tachikoma/issues/26) | [PL-16](#pl-16) ×1 |
| `HW-Mouth_Ball_Bored`<br>[Mouth_Ball_Bored.stl](../hardware/stl/Mouth_Ball_Bored.stl) | 1<br>共通/標準 | PLA グレー / 壁2, 8% | 0 個（旧記録）。旧計画の未印刷群。以後の現物数は未確認。 | 未確定（現設計なら 0〜1）。実マイク/スピーカー寸法と嵌合を確定→該当部品 1 個の挿入・配線試験。Ball/Neck/Cannon と Cap/Key/Peg の全体を確認。 | [P-02](https://github.com/hapx2yuki/Tachikoma/issues/12) / [P-06](https://github.com/hapx2yuki/Tachikoma/issues/16) / [RV-08](https://github.com/hapx2yuki/Tachikoma/issues/89)<br>印刷: [PR-07](https://github.com/hapx2yuki/Tachikoma/issues/25) | [PL-17](#pl-17) ×1（同居品に不一致） |
| `HW-Mouth_Cannon_Bored`<br>[Mouth_Cannon_Bored.stl](../hardware/stl/Mouth_Cannon_Bored.stl)<br>**今回の形状変更**。マイク挿入経路とキーの通路を修正。キーの固定嵌合は RV-08 で別途確認。 | 1<br>共通/標準 | PLA グレー / 壁2, 8% | 0 個（旧記録）。旧計画の未印刷群。以後の現物数は未確認。 | 未確定（現設計なら 0〜1）。実マイク/スピーカー寸法と嵌合を確定→該当部品 1 個の挿入・配線試験。Ball/Neck/Cannon と Cap/Key/Peg の全体を確認。 | [P-02](https://github.com/hapx2yuki/Tachikoma/issues/12) / [P-06](https://github.com/hapx2yuki/Tachikoma/issues/16) / [RV-08](https://github.com/hapx2yuki/Tachikoma/issues/89)<br>印刷: [PR-07](https://github.com/hapx2yuki/Tachikoma/issues/25) | [PL-17](#pl-17) ×1 **不一致** |
| `HW-Mouth_Neck_Bored`<br>[Mouth_Neck_Bored.stl](../hardware/stl/Mouth_Neck_Bored.stl)<br>**今回の形状変更**。Ball/Cap の受け座を内部切削。旧形状そのままの組立は不可。 | 1<br>共通/標準 | PLA 青 / 壁2, 8% | 1 個（旧記録）。Blue_2 で印刷済みという旧記録。現 Blue_2 には未収録。今回内部加工変更。 | 未確定（現設計なら 0〜1）。実マイク/スピーカー寸法と嵌合を確定→該当部品 1 個の挿入・配線試験。Ball/Neck/Cannon と Cap/Key/Peg の全体を確認。 | [P-02](https://github.com/hapx2yuki/Tachikoma/issues/12) / [P-06](https://github.com/hapx2yuki/Tachikoma/issues/16) / [RV-08](https://github.com/hapx2yuki/Tachikoma/issues/89)<br>印刷: [PR-07](https://github.com/hapx2yuki/Tachikoma/issues/25) | **未収録**。現 STL を別名プレートへ。 |
| `HW-audio_cradle_mic`<br>[audio_cradle_mic.stl](../hardware/stl/audio_cradle_mic.stl) | 1<br>共通/標準 | PETG / 壁4, 40%, レイヤー0.12 | 1 個（旧記録）。Walk_1。旧記録は層 0.2mm。現指定 0.12mm と違うが嵌合が良ければ自動廃棄しない。 | 未確定（現設計なら 0〜1）。旧 0.2mm 層品で基板の出入れと保持を先に試す。不適合なら 0.12mm 層の 1 個に置換。 | [P-02](https://github.com/hapx2yuki/Tachikoma/issues/12) / [P-06](https://github.com/hapx2yuki/Tachikoma/issues/16) / [RV-08](https://github.com/hapx2yuki/Tachikoma/issues/89)<br>印刷: [PR-07](https://github.com/hapx2yuki/Tachikoma/issues/25) | [PL-06](#pl-06) ×1 / [PL-07](#pl-07) ×1（同居品に不一致） |
| `HW-audio_cradle_spk`<br>[audio_cradle_spk.stl](../hardware/stl/audio_cradle_spk.stl) | 1<br>共通/標準 | PETG / 壁4, 40% | 0 個（旧記録）。旧計画の未印刷群。以後の現物数は未確認。 | 未確定（現設計なら 0〜1）。実マイク/スピーカー寸法と嵌合を確定→該当部品 1 個の挿入・配線試験。Ball/Neck/Cannon と Cap/Key/Peg の全体を確認。 | [P-02](https://github.com/hapx2yuki/Tachikoma/issues/12) / [P-06](https://github.com/hapx2yuki/Tachikoma/issues/16) / [RV-08](https://github.com/hapx2yuki/Tachikoma/issues/89)<br>印刷: [PR-07](https://github.com/hapx2yuki/Tachikoma/issues/25) | [PL-02](#pl-02) ×1（同居品に不一致） / [PL-10](#pl-10) ×1（同居品に不一致） |
| `HW-camera_carrier`<br>[camera_carrier.stl](../hardware/stl/camera_carrier.stl) | 1<br>共通/標準 | PETG / 壁4, 40% | 0 個（旧記録）。旧計画の未印刷群。以後の現物数は未確認。 | 未確定（現設計なら 0〜1）。実基板/短 FPC を同定し採用カメラ設計を選ぶ。試験用 1 式だけ。旧 base 予備の 2 個は自動補充しない。 | [P-02](https://github.com/hapx2yuki/Tachikoma/issues/12) / [P-07](https://github.com/hapx2yuki/Tachikoma/issues/17) / [H-02](https://github.com/hapx2yuki/Tachikoma/issues/51) / [RV-09](https://github.com/hapx2yuki/Tachikoma/issues/90)<br>印刷: [PR-06](https://github.com/hapx2yuki/Tachikoma/issues/24) | [PL-05](#pl-05) ×1（同居品に不一致） / [PL-10](#pl-10) ×1（同居品に不一致） |
| `HW-chassis`<br>[chassis.stl](../hardware/stl/chassis.stl)<br>**今回の形状変更**。Mouth の内部逃げに加えて前方 90° の穴周りへ厚さ 3mm を追加。削るだけでは同等にならず、頭支持 RV-13 と合わせて再使用を設計判断する。 | 1<br>共通/標準 | PETG / 壁4, インフィル25%グリッド | 1 個（旧記録）。Walk_1。今回の内部逃げと前方カラー追加前。 | 未確定（現設計なら 0〜1）。頭サーボ配置と支持部を確定→旧品の隠し加工/補強可否を P-05 で判定→必要なら新 1 個。 | [P-02](https://github.com/hapx2yuki/Tachikoma/issues/12) / [RV-09](https://github.com/hapx2yuki/Tachikoma/issues/90) / [RV-13](https://github.com/hapx2yuki/Tachikoma/issues/94) / [P-03](https://github.com/hapx2yuki/Tachikoma/issues/13) / [P-04](https://github.com/hapx2yuki/Tachikoma/issues/14) / [P-05](https://github.com/hapx2yuki/Tachikoma/issues/15) / [RV-14](https://github.com/hapx2yuki/Tachikoma/issues/95)<br>印刷: [PR-09](https://github.com/hapx2yuki/Tachikoma/issues/27) | [PL-02](#pl-02) ×1 **不一致** / [PL-07](#pl-07) ×1 **不一致** |
| `HW-eye_carrier`<br>[eye_carrier.stl](../hardware/stl/eye_carrier.stl) | 2<br>共通/標準 | PETG / 壁4, 40% | 0 個（旧記録）。旧計画の未印刷群。以後の現物数は未確認。 | 未確定（現設計なら 0〜2）。既存 eye_pod を流用し片目 1 式を実サーボで試験→左右の不足分。固定部ケースの収納は別途確認。 | [P-02](https://github.com/hapx2yuki/Tachikoma/issues/12) / [P-03](https://github.com/hapx2yuki/Tachikoma/issues/13) / [P-04](https://github.com/hapx2yuki/Tachikoma/issues/14) / [RV-09](https://github.com/hapx2yuki/Tachikoma/issues/90) / [H-01](https://github.com/hapx2yuki/Tachikoma/issues/50)<br>印刷: [PR-06](https://github.com/hapx2yuki/Tachikoma/issues/24) | [PL-02](#pl-02) ×2（同居品に不一致） / [PL-10](#pl-10) ×2（同居品に不一致） |
| `HW-eye_pod`<br>[eye_pod.stl](../hardware/stl/eye_pod.stl) | 2<br>共通/標準 | PLA 白 / 壁2, 8% (LED 透過) | 2 個（旧記録）。White。 | 未確定（現設計なら 0〜2）。既存 eye_pod を流用し片目 1 式を実サーボで試験→左右の不足分。固定部ケースの収納は別途確認。 | [P-02](https://github.com/hapx2yuki/Tachikoma/issues/12) / [P-03](https://github.com/hapx2yuki/Tachikoma/issues/13) / [P-04](https://github.com/hapx2yuki/Tachikoma/issues/14) / [RV-09](https://github.com/hapx2yuki/Tachikoma/issues/90) / [H-01](https://github.com/hapx2yuki/Tachikoma/issues/50)<br>印刷: [PR-06](https://github.com/hapx2yuki/Tachikoma/issues/24) | [PL-19](#pl-19) ×2 |
| `HW-eye_pod_camera_base`<br>[eye_pod_camera_base.stl](../hardware/stl/eye_pod_camera_base.stl) | 1<br>共通/標準 | PLA 白 / 壁2, 8% | 3 個（旧記録）。White の 1 個＋予備 2 個という旧記録。9/4 に旧ポケット版と記載。実数と改訂版の有無は未確認。 | 未確定（現設計なら 0〜1）。実基板/短 FPC を同定し採用カメラ設計を選ぶ。試験用 1 式だけ。旧 base 予備の 2 個は自動補充しない。 | [P-02](https://github.com/hapx2yuki/Tachikoma/issues/12) / [P-07](https://github.com/hapx2yuki/Tachikoma/issues/17) / [H-02](https://github.com/hapx2yuki/Tachikoma/issues/51) / [RV-09](https://github.com/hapx2yuki/Tachikoma/issues/90)<br>印刷: [PR-10](https://github.com/hapx2yuki/Tachikoma/issues/79) | [PL-19](#pl-19) ×1 / [PL-21](#pl-21) ×1 / [PL-25](#pl-25) ×2 |
| `HW-eye_pod_camera_shell`<br>[eye_pod_camera_shell.stl](../hardware/stl/eye_pod_camera_shell.stl) | 1<br>共通/標準 | PLA 白 / 壁2, 8% | 1 個（旧記録）。White。現物カメラの種類次第で内部変更の可能性。 | 未確定（現設計なら 0〜1）。実基板/短 FPC を同定し採用カメラ設計を選ぶ。試験用 1 式だけ。旧 base 予備の 2 個は自動補充しない。 | [P-02](https://github.com/hapx2yuki/Tachikoma/issues/12) / [P-07](https://github.com/hapx2yuki/Tachikoma/issues/17) / [H-02](https://github.com/hapx2yuki/Tachikoma/issues/51) / [RV-09](https://github.com/hapx2yuki/Tachikoma/issues/90)<br>印刷: [PR-06](https://github.com/hapx2yuki/Tachikoma/issues/24) | [PL-19](#pl-19) ×1 |
| `KIT-Head_Dome_Grey`<br>[Head_Dome_Grey.stl](../model/Head_Dome_Grey.stl) | 1<br>共通/標準 | PLA グレー / 壁2, 8% | 0 個（旧記録）。旧計画の未印刷群。以後の現物数は未確認。 | 未確定（現設計なら 0〜1）。形状変更・既知実交差なし。不足なら各 1 個を元の相手部品へ仮合わせ。頭全体の組立合格とはしない。 | [P-02](https://github.com/hapx2yuki/Tachikoma/issues/12)<br>印刷: [PR-01](https://github.com/hapx2yuki/Tachikoma/issues/19) | [PL-18](#pl-18) ×1 |
| `KIT-Head_Insert_Black_x4`<br>[Head_Insert_Black_x4.stl](../model/Head_Insert_Black_x4.stl) | 4<br>共通/標準 | PLA 黒 / 壁2, 8% | 0 個（旧記録）。旧計画の未印刷群。以後の現物数は未確認。 | 未確定（現設計なら 0〜4）。元配置が不明/実交差あり。配置・接合を確定後に不足 1 個を仮合わせ→残数。 | [P-02](https://github.com/hapx2yuki/Tachikoma/issues/12) / [S-08](https://github.com/hapx2yuki/Tachikoma/issues/67) / [RV-09](https://github.com/hapx2yuki/Tachikoma/issues/90)<br>印刷: [PR-02](https://github.com/hapx2yuki/Tachikoma/issues/20) | [PL-11](#pl-11) ×4 |
| `KIT-Head_Peg_Lower`<br>[Head_Peg_Lower.stl](../model/Head_Peg_Lower.stl) | 1<br>共通/標準 | PLA グレー / 壁2, 15% | 0 個（旧記録）。旧計画の未印刷群。以後の現物数は未確認。 | 未確定（現設計なら 0〜1）。頭の積層と支持柱が成立後、旧ペグ座を使うか確定し各 1 個。 | [P-02](https://github.com/hapx2yuki/Tachikoma/issues/12) / [RV-09](https://github.com/hapx2yuki/Tachikoma/issues/90) / [RV-13](https://github.com/hapx2yuki/Tachikoma/issues/94)<br>印刷: [PR-01](https://github.com/hapx2yuki/Tachikoma/issues/19) | [PL-18](#pl-18) ×1 |
| `KIT-Head_Peg_Upper`<br>[Head_Peg_Upper.stl](../model/Head_Peg_Upper.stl) | 1<br>共通/標準 | PLA グレー / 壁2, 15% | 0 個（旧記録）。旧計画の未印刷群。以後の現物数は未確認。 | 未確定（現設計なら 0〜1）。頭の積層と支持柱が成立後、旧ペグ座を使うか確定し各 1 個。 | [P-02](https://github.com/hapx2yuki/Tachikoma/issues/12) / [RV-09](https://github.com/hapx2yuki/Tachikoma/issues/90) / [RV-13](https://github.com/hapx2yuki/Tachikoma/issues/94)<br>印刷: [PR-01](https://github.com/hapx2yuki/Tachikoma/issues/19) | [PL-18](#pl-18) ×1 |
| `KIT-Head_Plug_Grey`<br>[Head_Plug_Grey.stl](../model/Head_Plug_Grey.stl) | 1<br>共通/標準 | PLA グレー / 壁2, 8% | 0 個（旧記録）。旧計画の未印刷群。以後の現物数は未確認。 | 未確定（現設計なら 0〜1）。形状変更・既知実交差なし。不足なら各 1 個を元の相手部品へ仮合わせ。頭全体の組立合格とはしない。 | [P-02](https://github.com/hapx2yuki/Tachikoma/issues/12)<br>印刷: [PR-01](https://github.com/hapx2yuki/Tachikoma/issues/19) | [PL-18](#pl-18) ×1 |
| `KIT-Head_Screw_Grey_x2`<br>[Head_Screw_Grey_x2.stl](../model/Head_Screw_Grey_x2.stl) | 2<br>共通/標準 | PLA グレー / 壁2, 8% | 0 個（旧記録）。旧計画の未印刷群。以後の現物数は未確認。 | 未確定（現設計なら 0〜2）。元配置が不明/実交差あり。配置・接合を確定後に不足 1 個を仮合わせ→残数。 | [P-02](https://github.com/hapx2yuki/Tachikoma/issues/12) / [S-08](https://github.com/hapx2yuki/Tachikoma/issues/67) / [RV-09](https://github.com/hapx2yuki/Tachikoma/issues/90)<br>印刷: [PR-01](https://github.com/hapx2yuki/Tachikoma/issues/19) | [PL-18](#pl-18) ×2 |
| `KIT-Mouth_Cap_Grey`<br>[Mouth_Cap_Grey.stl](../model/Mouth_Cap_Grey.stl) | 1<br>共通/標準 | PLA グレー / 壁2, 8% | 0 個（旧記録）。旧計画の未印刷群。以後の現物数は未確認。 | 未確定（現設計なら 0〜1）。実マイク/スピーカー寸法と嵌合を確定→該当部品 1 個の挿入・配線試験。Ball/Neck/Cannon と Cap/Key/Peg の全体を確認。 | [P-02](https://github.com/hapx2yuki/Tachikoma/issues/12) / [P-06](https://github.com/hapx2yuki/Tachikoma/issues/16) / [RV-08](https://github.com/hapx2yuki/Tachikoma/issues/89)<br>印刷: [PR-01](https://github.com/hapx2yuki/Tachikoma/issues/19) | [PL-18](#pl-18) ×1 |
| `KIT-Mouth_Key_Grey`<br>[Mouth_Key_Grey.stl](../model/Mouth_Key_Grey.stl) | 1<br>共通/標準 | PLA グレー / 壁2, 8% | 0 個（旧記録）。旧計画の未印刷群。以後の現物数は未確認。 | 未確定（現設計なら 0〜1）。実マイク/スピーカー寸法と嵌合を確定→該当部品 1 個の挿入・配線試験。Ball/Neck/Cannon と Cap/Key/Peg の全体を確認。 | [P-02](https://github.com/hapx2yuki/Tachikoma/issues/12) / [P-06](https://github.com/hapx2yuki/Tachikoma/issues/16) / [RV-08](https://github.com/hapx2yuki/Tachikoma/issues/89)<br>印刷: [PR-01](https://github.com/hapx2yuki/Tachikoma/issues/19) | [PL-18](#pl-18) ×1 |
| `KIT-Mouth_Peg_Grey`<br>[Mouth_Peg_Grey.stl](../model/Mouth_Peg_Grey.stl) | 1<br>共通/標準 | PLA グレー / 壁2, 8% | 0 個（旧記録）。旧計画の未印刷群。以後の現物数は未確認。 | 未確定（現設計なら 0〜1）。実マイク/スピーカー寸法と嵌合を確定→該当部品 1 個の挿入・配線試験。Ball/Neck/Cannon と Cap/Key/Peg の全体を確認。 | [P-02](https://github.com/hapx2yuki/Tachikoma/issues/12) / [P-06](https://github.com/hapx2yuki/Tachikoma/issues/16) / [RV-08](https://github.com/hapx2yuki/Tachikoma/issues/89)<br>印刷: [PR-01](https://github.com/hapx2yuki/Tachikoma/issues/19) | [PL-18](#pl-18) ×1 |

## Cabin・首・装飾・予備

| 部品 ID・STL | 必要数／標準・鏡像 | 材質・設定 | 旧印刷記録 | 追加・試験順序 | 先行確認／印刷 Issue | 現 3MF |
|---|---|---|---|---|---|---|
| `HW-pod_neck`<br>[pod_neck.stl](../hardware/stl/pod_neck.stl) | 1<br>共通/標準 | PETG / 壁4, 40% | 0 個（旧記録）。旧計画の未印刷群。以後の現物数は未確認。 | 未確定（現設計なら 0〜1）。首全長と Cabin 電装室/装飾の成立後に候補 1 本で荷重・挿入確認。現在の梁を追加量産しない。 | [P-02](https://github.com/hapx2yuki/Tachikoma/issues/12) / [RV-15](https://github.com/hapx2yuki/Tachikoma/issues/96) / [H-06](https://github.com/hapx2yuki/Tachikoma/issues/55) / [RV-07](https://github.com/hapx2yuki/Tachikoma/issues/88)<br>印刷: [PR-06](https://github.com/hapx2yuki/Tachikoma/issues/24) | [PL-03](#pl-03) ×1 / [PL-10](#pl-10) ×1（同居品に不一致） |
| `KIT-Cabin_Back_Blue_Repaired`<br>[Cabin_Back_Blue_Repaired.stl](../model/Cabin_Back_Blue_Repaired.stl)<br>殻の Z 配置 -6.3075mm の訂正だけ。元 STL 不変で再印刷理由ではない。内部電装室の採否は別。 | 1<br>共通/標準 | PLA 青 / 壁2, 8% | 1 個（旧記録）。Blue_4。今回 Z 配置訂正だけで原 STL は不変。 | 未確定（現設計なら 0〜1）。既存 1 個を保全。内部のみの追加工/交換が決定したときだけ試作 1 個。CabinBack の配置訂正だけなら再印刷 0。 | [P-02](https://github.com/hapx2yuki/Tachikoma/issues/12) / [RV-15](https://github.com/hapx2yuki/Tachikoma/issues/96) / [H-06](https://github.com/hapx2yuki/Tachikoma/issues/55)<br>印刷: [RV-15](https://github.com/hapx2yuki/Tachikoma/issues/96) | [PL-15](#pl-15) ×1 |
| `KIT-Cabin_Eye_White`<br>[Cabin_Eye_White.stl](../model/Cabin_Eye_White.stl) | 1<br>共通/標準 | PLA 白 / 壁2, 8% | 1 個（旧記録）。White_2。内部収納・梁との交差は未解決。 | 未確定（現設計なら 0〜1）。既存 1 個を保全。内部のみの追加工/交換が決定したときだけ試作 1 個。CabinBack の配置訂正だけなら再印刷 0。 | [P-02](https://github.com/hapx2yuki/Tachikoma/issues/12) / [RV-15](https://github.com/hapx2yuki/Tachikoma/issues/96) / [H-06](https://github.com/hapx2yuki/Tachikoma/issues/55)<br>印刷: [RV-15](https://github.com/hapx2yuki/Tachikoma/issues/96) | [PL-20](#pl-20) ×1 |
| `KIT-Cabin_Front_Blue`<br>[Cabin_Front_Blue.stl](../model/Cabin_Front_Blue.stl) | 1<br>共通/標準 | PLA 青 / 壁2, 8% | 1 個（旧記録）。Blue_3。内部電装室と通線は未加工。 | 未確定（現設計なら 0〜1）。既存 1 個を保全。内部のみの追加工/交換が決定したときだけ試作 1 個。CabinBack の配置訂正だけなら再印刷 0。 | [P-02](https://github.com/hapx2yuki/Tachikoma/issues/12) / [RV-15](https://github.com/hapx2yuki/Tachikoma/issues/96) / [H-06](https://github.com/hapx2yuki/Tachikoma/issues/55)<br>印刷: [RV-15](https://github.com/hapx2yuki/Tachikoma/issues/96) | [PL-14](#pl-14) ×1 |
| `KIT-Cabin_Front_Insert_Back_Black_x2`<br>[Cabin_Front_Insert_Back_Black_x2.stl](../model/Cabin_Front_Insert_Back_Black_x2.stl) | 2<br>共通/標準 | PLA 黒 / 壁2, 8% | 0 個（旧記録）。旧計画の未印刷群。以後の現物数は未確認。 | 未確定（現設計なら 0〜2）。不足かつ使用設計が確定した場合に 1 個→嵌合確認→必要残数。既存良品があれば試験にも流用。 | [P-02](https://github.com/hapx2yuki/Tachikoma/issues/12) / [RV-15](https://github.com/hapx2yuki/Tachikoma/issues/96) / [H-06](https://github.com/hapx2yuki/Tachikoma/issues/55)<br>印刷: [PR-02](https://github.com/hapx2yuki/Tachikoma/issues/20) | [PL-11](#pl-11) ×2 |
| `KIT-Cabin_Front_Insert_Bottom_Long_Black_x2`<br>[Cabin_Front_Insert_Bottom_Long_Black_x2.stl](../model/Cabin_Front_Insert_Bottom_Long_Black_x2.stl) | 2<br>共通/標準 | PLA 黒 / 壁2, 8% | 0 個（旧記録）。旧計画の未印刷群。以後の現物数は未確認。 | 未確定（現設計なら 0〜2）。不足かつ使用設計が確定した場合に 1 個→嵌合確認→必要残数。既存良品があれば試験にも流用。 | [P-02](https://github.com/hapx2yuki/Tachikoma/issues/12) / [RV-15](https://github.com/hapx2yuki/Tachikoma/issues/96) / [H-06](https://github.com/hapx2yuki/Tachikoma/issues/55)<br>印刷: [PR-02](https://github.com/hapx2yuki/Tachikoma/issues/20) | [PL-11](#pl-11) ×2 |
| `KIT-Cabin_Front_Insert_Bottom_Wide_Black`<br>[Cabin_Front_Insert_Bottom_Wide_Black.stl](../model/Cabin_Front_Insert_Bottom_Wide_Black.stl) | 1<br>共通/標準 | PLA 黒 / 壁2, 8% | 0 個（旧記録）。旧計画の未印刷群。以後の現物数は未確認。 | 未確定（現設計なら 0〜1）。不足かつ使用設計が確定した場合に 1 個→嵌合確認→必要残数。既存良品があれば試験にも流用。 | [P-02](https://github.com/hapx2yuki/Tachikoma/issues/12) / [RV-15](https://github.com/hapx2yuki/Tachikoma/issues/96) / [H-06](https://github.com/hapx2yuki/Tachikoma/issues/55)<br>印刷: [PR-02](https://github.com/hapx2yuki/Tachikoma/issues/20) | [PL-11](#pl-11) ×1 |
| `KIT-Cabin_Front_Insert_Front_Black`<br>[Cabin_Front_Insert_Front_Black.stl](../model/Cabin_Front_Insert_Front_Black.stl) | 1<br>共通/標準 | PLA 黒 / 壁2, 8% | 0 個（旧記録）。旧計画の未印刷群。以後の現物数は未確認。 | 未確定（現設計なら 0〜1）。不足かつ使用設計が確定した場合に 1 個→嵌合確認→必要残数。既存良品があれば試験にも流用。 | [P-02](https://github.com/hapx2yuki/Tachikoma/issues/12) / [RV-15](https://github.com/hapx2yuki/Tachikoma/issues/96) / [H-06](https://github.com/hapx2yuki/Tachikoma/issues/55)<br>印刷: [PR-02](https://github.com/hapx2yuki/Tachikoma/issues/20) | [PL-11](#pl-11) ×1 |
| `KIT-Cabin_Front_Insert_Left_Black`<br>[Cabin_Front_Insert_Left_Black.stl](../model/Cabin_Front_Insert_Left_Black.stl) | 1<br>共通/標準 | PLA 黒 / 壁2, 8% | 0 個（旧記録）。旧計画の未印刷群。以後の現物数は未確認。 | 未確定（現設計なら 0〜1）。不足かつ使用設計が確定した場合に 1 個→嵌合確認→必要残数。既存良品があれば試験にも流用。 | [P-02](https://github.com/hapx2yuki/Tachikoma/issues/12) / [RV-15](https://github.com/hapx2yuki/Tachikoma/issues/96) / [H-06](https://github.com/hapx2yuki/Tachikoma/issues/55)<br>印刷: [PR-02](https://github.com/hapx2yuki/Tachikoma/issues/20) | [PL-11](#pl-11) ×1 |
| `KIT-Cabin_Front_Insert_Right_Black`<br>[Cabin_Front_Insert_Right_Black.stl](../model/Cabin_Front_Insert_Right_Black.stl) | 1<br>共通/標準 | PLA 黒 / 壁2, 8% | 0 個（旧記録）。旧計画の未印刷群。以後の現物数は未確認。 | 未確定（現設計なら 0〜1）。不足かつ使用設計が確定した場合に 1 個→嵌合確認→必要残数。既存良品があれば試験にも流用。 | [P-02](https://github.com/hapx2yuki/Tachikoma/issues/12) / [RV-15](https://github.com/hapx2yuki/Tachikoma/issues/96) / [H-06](https://github.com/hapx2yuki/Tachikoma/issues/55)<br>印刷: [PR-02](https://github.com/hapx2yuki/Tachikoma/issues/20) | [PL-11](#pl-11) ×1 |
| `KIT-Cabin_Peg_x2`<br>[Cabin_Peg_x2.stl](../model/Cabin_Peg_x2.stl) | 2<br>共通/標準 | PLA グレー / 壁2, 15% | 0 個（旧記録）。旧計画の未印刷群。以後の現物数は未確認。 | 未確定（現設計なら 0〜2）。原型 Peg 2 個の嵌合を先に確認。Cabin 候補の交換ラッチ 2 個と両方印刷しない。 | [P-02](https://github.com/hapx2yuki/Tachikoma/issues/12) / [RV-15](https://github.com/hapx2yuki/Tachikoma/issues/96) / [H-06](https://github.com/hapx2yuki/Tachikoma/issues/55)<br>印刷: [PR-01](https://github.com/hapx2yuki/Tachikoma/issues/19) | [PL-18](#pl-18) ×2 |
| `KIT-Cabin_RedLight_Large_Red_x4`<br>[Cabin_RedLight_Large_Red_x4.stl](../model/Cabin_RedLight_Large_Red_x4.stl) | 4<br>共通/標準 | PLA 赤 / 壁2, 8% | 0 個（旧記録）。旧計画の未印刷群。以後の現物数は未確認。 | 未確定（現設計なら 0〜4）。不足かつ使用設計が確定した場合に 1 個→嵌合確認→必要残数。既存良品があれば試験にも流用。 | [P-02](https://github.com/hapx2yuki/Tachikoma/issues/12) / [RV-15](https://github.com/hapx2yuki/Tachikoma/issues/96) / [H-06](https://github.com/hapx2yuki/Tachikoma/issues/55)<br>印刷: [PR-03](https://github.com/hapx2yuki/Tachikoma/issues/21) | [PL-22](#pl-22) ×4 |
| `KIT-Cabin_RedLight_Small_Red_x4`<br>[Cabin_RedLight_Small_Red_x4.stl](../model/Cabin_RedLight_Small_Red_x4.stl) | 4<br>共通/標準 | PLA 赤 / 壁2, 8% | 0 個（旧記録）。旧計画の未印刷群。以後の現物数は未確認。 | 未確定（現設計なら 0〜4）。不足があれば小ランプ 1 個を既存 Cabin に仮合わせ→良品残数最大 3。大ランプ側の未解決干渉とは別管理。 | [P-02](https://github.com/hapx2yuki/Tachikoma/issues/12)<br>印刷: [PR-03](https://github.com/hapx2yuki/Tachikoma/issues/21) | [PL-22](#pl-22) ×4 |
| `KIT-Cabin_Spinnarette_Grey_x4`<br>[Cabin_Spinnarette_Grey_x4.stl](../model/Cabin_Spinnarette_Grey_x4.stl) | 4<br>共通/標準 | PLA グレー / 壁2, 8% | 0 個（旧記録）。旧計画の未印刷群。以後の現物数は未確認。 | 未確定（現設計なら 0〜4）。不足かつ使用設計が確定した場合に 1 個→嵌合確認→必要残数。既存良品があれば試験にも流用。 | [P-02](https://github.com/hapx2yuki/Tachikoma/issues/12) / [RV-15](https://github.com/hapx2yuki/Tachikoma/issues/96) / [H-06](https://github.com/hapx2yuki/Tachikoma/issues/55)<br>印刷: [PR-01](https://github.com/hapx2yuki/Tachikoma/issues/19) | [PL-18](#pl-18) ×4 |
| `KIT-Cabin_Turrent_Left_Grey`<br>[Cabin_Turrent_Left_Grey.stl](../model/Cabin_Turrent_Left_Grey.stl) | 1<br>共通/標準 | PLA グレー / 壁2, 8% | 0 個（旧記録）。旧計画の未印刷群。以後の現物数は未確認。 | 未確定（現設計なら 0〜1）。不足かつ使用設計が確定した場合に 1 個→嵌合確認→必要残数。既存良品があれば試験にも流用。 | [P-02](https://github.com/hapx2yuki/Tachikoma/issues/12) / [RV-15](https://github.com/hapx2yuki/Tachikoma/issues/96) / [H-06](https://github.com/hapx2yuki/Tachikoma/issues/55)<br>印刷: [PR-01](https://github.com/hapx2yuki/Tachikoma/issues/19) | [PL-18](#pl-18) ×1 |
| `KIT-Cabin_Turrent_Right_Grey`<br>[Cabin_Turrent_Right_Grey.stl](../model/Cabin_Turrent_Right_Grey.stl) | 1<br>共通/標準 | PLA グレー / 壁2, 8% | 0 個（旧記録）。旧計画の未印刷群。以後の現物数は未確認。 | 未確定（現設計なら 0〜1）。不足かつ使用設計が確定した場合に 1 個→嵌合確認→必要残数。既存良品があれば試験にも流用。 | [P-02](https://github.com/hapx2yuki/Tachikoma/issues/12) / [RV-15](https://github.com/hapx2yuki/Tachikoma/issues/96) / [H-06](https://github.com/hapx2yuki/Tachikoma/issues/55)<br>印刷: [PR-01](https://github.com/hapx2yuki/Tachikoma/issues/19) | [PL-18](#pl-18) ×1 |
| `KIT-Cabin_Turret_Peg_x2`<br>[Cabin_Turret_Peg_x2.stl](../model/Cabin_Turret_Peg_x2.stl) | 2<br>共通/標準 | PLA グレー / 壁2, 15% | 0 個（旧記録）。旧計画の未印刷群。以後の現物数は未確認。 | 未確定（現設計なら 0〜2）。不足かつ使用設計が確定した場合に 1 個→嵌合確認→必要残数。既存良品があれば試験にも流用。 | [P-02](https://github.com/hapx2yuki/Tachikoma/issues/12) / [RV-15](https://github.com/hapx2yuki/Tachikoma/issues/96) / [H-06](https://github.com/hapx2yuki/Tachikoma/issues/55)<br>印刷: [PR-01](https://github.com/hapx2yuki/Tachikoma/issues/19) | [PL-18](#pl-18) ×2 |
| `KIT-Head_TailJoint_Ball_Grey_Optional_Cross`<br>[Head_TailJoint_Ball_Grey_Optional_Cross.stl](../model/Head_TailJoint_Ball_Grey_Optional_Cross.stl) | 1<br>共通/標準 | PLA グレー / 壁2, 8% | 0 個（旧記録）。旧計画の未印刷群。以後の現物数は未確認。 | 未確定（現設計なら 0〜1）。不足かつ使用設計が確定した場合に 1 個→嵌合確認→必要残数。既存良品があれば試験にも流用。 | [P-02](https://github.com/hapx2yuki/Tachikoma/issues/12) / [RV-15](https://github.com/hapx2yuki/Tachikoma/issues/96) / [H-06](https://github.com/hapx2yuki/Tachikoma/issues/55)<br>印刷: [PR-01](https://github.com/hapx2yuki/Tachikoma/issues/19) | [PL-18](#pl-18) ×1 |
| `KIT-Head_TailJoint_Blue_Optional_Cross`<br>[Head_TailJoint_Blue_Optional_Cross.stl](../model/Head_TailJoint_Blue_Optional_Cross.stl) | 1<br>共通/標準 | PLA 青 / 壁2, 8% | 1 個（旧記録）。Blue_4。現梁との組付け交差は未解決。 | 未確定（現設計なら 0〜1）。不足かつ使用設計が確定した場合に 1 個→嵌合確認→必要残数。既存良品があれば試験にも流用。 | [P-02](https://github.com/hapx2yuki/Tachikoma/issues/12) / [RV-15](https://github.com/hapx2yuki/Tachikoma/issues/96) / [H-06](https://github.com/hapx2yuki/Tachikoma/issues/55)<br>印刷: [PR-01](https://github.com/hapx2yuki/Tachikoma/issues/19) | [PL-15](#pl-15) ×1 |
| `KIT-Head_TailJoint_Peg`<br>[Head_TailJoint_Peg.stl](../model/Head_TailJoint_Peg.stl) | 1（予備）<br>共通/標準 | PLA グレー / 壁2, 15% | 0 個（旧記録）。旧計画の未印刷群。以後の現物数は未確認。 | 未確定（現設計なら 0〜1）。組立では使わない。元キット予備を保存したい場合のみ、不足 1 個を任意印刷。 | [P-02](https://github.com/hapx2yuki/Tachikoma/issues/12)<br>印刷: [PR-01](https://github.com/hapx2yuki/Tachikoma/issues/19) | [PL-18](#pl-18) ×1 |
| `KIT-Head_TailJoint_Peg_Optional_Cross_Repaired`<br>[Head_TailJoint_Peg_Optional_Cross_Repaired.stl](../model/Head_TailJoint_Peg_Optional_Cross_Repaired.stl) | 1（予備）<br>共通/標準 | PLA グレー / 壁2, 15% | 0 個（旧記録）。旧計画の未印刷群。以後の現物数は未確認。 | 未確定（現設計なら 0〜1）。組立では使わない。元キット予備を保存したい場合のみ、不足 1 個を任意印刷。 | [P-02](https://github.com/hapx2yuki/Tachikoma/issues/12)<br>印刷: [PR-01](https://github.com/hapx2yuki/Tachikoma/issues/19) | [PL-18](#pl-18) ×1 |
| `KIT-Stand_mount_Optional`<br>[Stand_mount_Optional.stl](../model/Stand_mount_Optional.stl) | 任意 1<br>共通/標準 | PLA グレー / 壁2, 8% | 不明。任意治具。必要性・在庫とも未確認。 | 未確定、任意 0〜1。保持治具として使う必要が決まったときのみ 1 個。積載強度と固定法の確認が先。 | [P-02](https://github.com/hapx2yuki/Tachikoma/issues/12) | 現 27 プレート未収録 |

## 印刷しない原型・参照形状

元データの保全対象です。加工済み部品と二重に作らず、既印刷品を無断廃棄もしません。数量の衝突がある Left Guard は上の腕の表で別扱いです。

| 部品 ID・STL | 追加数 | 理由 |
|---|---:|---|
| `HW-eye_pod_camera`<br>[eye_pod_camera.stl](../hardware/stl/eye_pod_camera.stl) | 0 | 一体参照用。分割版 shell/base を使用する。 |
| `KIT-Arm_Left`<br>[Arm_Left.stl](../model/Arm_Left.stl) | 0 | 腕ポッドは arm_pod_upper/lower(+_L) に機能置換。加工ソースは `hardware/src/arm_shell.py` が読む Arm_Right.stl のみで、左腕用 (_L) はその鏡映生成 — 本ファイル自体はソースとしても使われない |
| `KIT-Arm_Left_Elbow_Grey`<br>[Arm_Left_Elbow_Grey.stl](../model/Arm_Left_Elbow_Grey.stl) | 0 | elbow_shell(+_L) に機能置換。加工ソースは Arm_Right_Elbow_Grey.stl のみ (`arm_shell.py`) — 本ファイルは未使用 |
| `KIT-Arm_Right`<br>[Arm_Right.stl](../model/Arm_Right.stl) | 0 | `arm_shell.py` が読み込み、arm_pod_upper/lower (+ 左腕分 _L の鏡映元) をブーリアン加工するソース |
| `KIT-Arm_Right_Claw_Grey`<br>[Arm_Right_Claw_Grey.stl](../model/Arm_Right_Claw_Grey.stl) | 0 | 爪ハブと無関係の別形状 (開放骨組, 体積/凸包比0.205)。爪ハブは Arm_Left_Claw_Grey のみ採用 (§2.5-5 に明記) |
| `KIT-Arm_Right_Elbow_Grey`<br>[Arm_Right_Elbow_Grey.stl](../model/Arm_Right_Elbow_Grey.stl) | 0 | `arm_shell.py` が読み込み、elbow_shell (+_L 鏡映元) をブーリアン加工するソース |
| `KIT-Head_Bottom_Blue`<br>[Head_Bottom_Blue.stl](../model/Head_Bottom_Blue.stl) | 0 | `hardware/src/make_head.py` が読み込み、Head_Bottom_Armcut (腕ソケット拡口+マウス配線受け穴) をブーリアン加工するソース |
| `KIT-Head_Bottom_Cap_Grey`<br>[Head_Bottom_Cap_Grey.stl](../model/Head_Bottom_Cap_Grey.stl) | 0 | 旧: Head 積層順最下段の底蓋。機構逃がしカット後の Head_Bottom_Armcut は底中央がバッテリー窓+挿入経路 (旧キャップ座 r7.5..20 は窓に消滅) で、装着するとバッテリー交換を塞ぐため不使用。§3 |
| `KIT-Head_Eye_White_x3`<br>[Head_Eye_White_x3.stl](../model/Head_Eye_White_x3.stl) | 0 | `make_eye.py`/`make_camera.py` が読み込み、eye_pod (×2, 左右) + eye_pod_camera (×1, 中央) の共通ブーリアン加工ソース。kit内3個を使い切る対応 |
| `KIT-Head_Plate_Grey`<br>[Head_Plate_Grey.stl](../model/Head_Plate_Grey.stl) | 0 | 旧: Top/Bottom 間に挟むガスケット円板。2026-08-20 の機構逃がしカット設計でこの層は**シャーシプレート自体が置き換える**ことが確定 (assembly.md §3「Head_Plate は印刷・使用しない」) — 表の更新が漏れていたのを是正。§3 |
| `KIT-Head_Top_Blue`<br>[Head_Top_Blue.stl](../model/Head_Top_Blue.stl) | 0 | `tools/make_head_eyecut.py` が読み込み、Head_Top_Eyecut (目ソケット底φ30貫通ボア) をブーリアン加工するソース |
| `KIT-Leg_AnkleJoint_Grey_x4_Repaired`<br>[Leg_AnkleJoint_Grey_x4_Repaired.stl](../model/Leg_AnkleJoint_Grey_x4_Repaired.stl) | 0 | 旧キットの球関節。本設計は tibia 先端に足 (leg_foot_bored) を直結するため不要 |
| `KIT-Leg_Foot_Grey_x4_Repaired`<br>[Leg_Foot_Grey_x4_Repaired.stl](../model/Leg_Foot_Grey_x4_Repaired.stl) | 0 | `make_leg.py` が読み込み、leg_foot_bored (差込プラグ+隠しパッドポケット追加) をブーリアン加工するソース |
| `KIT-Leg_HipJoint_Grey_x4`<br>[Leg_HipJoint_Grey_x4.stl](../model/Leg_HipJoint_Grey_x4.stl) | 0 | 股ヨー関節は coxa_bracket 骨格に機能置換 (任意でコーン外皮として縦割り被せ可、必須ではない) |
| `KIT-Leg_HipJoint_Socket_Grey_x4`<br>[Leg_HipJoint_Socket_Grey_x4.stl](../model/Leg_HipJoint_Socket_Grey_x4.stl) | 0 | 同上 |
| `KIT-Leg_KneeJoint_Grey_x4`<br>[Leg_KneeJoint_Grey_x4.stl](../model/Leg_KneeJoint_Grey_x4.stl) | 0 | 膝関節は femur_link/tibia_link 骨格に機能置換。膝露出カバーとしての流用も実測で不成立と判明 (露出48mm > パーツ最大辺30.2mm, docs/assembly.md §3 参照) — 膝はメカ剥き出しの見た目で確定、新規カバー形状も作らない |
| `KIT-Leg_Shin_Blue_x4`<br>[Leg_Shin_Blue_x4.stl](../model/Leg_Shin_Blue_x4.stl) | 0 | `shell_mod.py` が読み込み、shin_shell/_m をブーリアン加工するソース |
| `KIT-Leg_Thigh_Grey_x4`<br>[Leg_Thigh_Grey_x4.stl](../model/Leg_Thigh_Grey_x4.stl) | 0 | `shell_mod.py` が読み込み、thigh_cap をブーリアン加工するソース |
| `KIT-Mouth_Ball_Grey`<br>[Mouth_Ball_Grey.stl](../model/Mouth_Ball_Grey.stl) | 0 | `make_audio.py` が読み込み、Mouth_Ball_Bored をブーリアン加工するソース |
| `KIT-Mouth_Cannon_Grey`<br>[Mouth_Cannon_Grey.stl](../model/Mouth_Cannon_Grey.stl) | 0 | 同上、Mouth_Cannon_Bored のソース |
| `KIT-Mouth_Neck_Blue`<br>[Mouth_Neck_Blue.stl](../model/Mouth_Neck_Blue.stl) | 0 | `make_audio.py` が読み込み、Mouth_Neck_Bored をブーリアン加工するソース |

## 未採用候補は印刷指示に含めない

下記は修正候補の比較用データです。局所の数値試験を通ったものにも全体組立や現物試験の保留があります。候補の STL 数を、追加部品数へ足しません。部品の占有箱・FPC の模型・URDF メッシュ・断面検査用メッシュ、PNG/PDF の説明図は部品として印刷・計数しません。coxa の採用済み内部修正の比較履歴も、現 STL と二重には印刷しません。

| 候補 ID | ファイル群／採用時の個数候補 | 現在の扱い・先行確認 |
|---|---|---|
| `CAND-CABIN`<br>Cabin 電装室・棚・交換ラッチ | 14 STL。[候補の保存先](audits/20260905-round2/cabin-electronics/)。採用案を確定した場合の構成 6 個（追加数ではない）。 | 殻は PLA 青、棚・ばねペグは PETG の候補。積層向き/壁/充填率は採用前に試験で確定。 全体採用保留。内部電装室の局所試験合格は首・Eye・装飾込みの成立を意味しない。 [H-06](https://github.com/hapx2yuki/Tachikoma/issues/55) / [RV-15](https://github.com/hapx2yuki/Tachikoma/issues/96) |
| `CAND-CAMERA`<br>OV3660・XIAO 用の内部キャリア | 8 STL。[候補の保存先](audits/20260905-round2/camera-ov3660-candidate/)。採用案を確定した場合の構成 3 個（追加数ではない）。 | 外殻は PLA 白、キャリアは PETG の候補。XIAO 一体保持を含む最終設定は未確定。 現物基板を同定後に採否判断。shell 1＋carrier 1＋base 1 の置換候補。base 単体と XIAO 保持一体 base は択一。 [P-07](https://github.com/hapx2yuki/Tachikoma/issues/17) / [H-02](https://github.com/hapx2yuki/Tachikoma/issues/51) / [RV-09](https://github.com/hapx2yuki/Tachikoma/issues/90) |
| `CAND-FOOT`<br>トゥ下面 TPU 靴と隠し受け座 | 8 STL。[候補の保存先](audits/20260905-round2/foot-support-candidates/)。 | 靴は TPU 95A 黒、受け座を加工したトゥは元 PLA 黒を想定。最終印刷設定は未確定。 1.5mm 靴は比較モデル。FR 3 本の候補だけで、左右 4 脚の製造一式ではない。採用時は TPU 靴 12 個と既存トゥ 12 本の受け座加工/交換が候補。接着・滑り・爪根元荷重の実測待ち。球面パッド案と同時採用しない。 [RV-06](https://github.com/hapx2yuki/Tachikoma/issues/87) |
| `CAND-NECK`<br>首梁の局所補強 | 11 STL。[候補の保存先](audits/20260905-round2/neck-reinforcement-candidates/)。採用案を確定した場合の構成 1 個（追加数ではない）。 | PETG、壁 4/40% の近似も評価済み。実材料/積層強度は未測定。 11 変種は有限比較。局所強度と頭部逃げを満たす案も、Cabin/TailJoint/Eye との全長組立が未成立。採用候補を 1 本に絞ってから。 [RV-07](https://github.com/hapx2yuki/Tachikoma/issues/88) / [RV-15](https://github.com/hapx2yuki/Tachikoma/issues/96) |
| `CAND-WIRE`<br>首梁の φ6/φ8 通線 | 8 STL。[候補の保存先](audits/20260905-round2/neck-wire-candidates/)。 | PETG 梁への通線比較。単独の印刷対象ではない。 8 変種は比較履歴。首補強案に統合される検討であり、8 本の追加部品ではない。 [RV-07](https://github.com/hapx2yuki/Tachikoma/issues/88) / [RV-15](https://github.com/hapx2yuki/Tachikoma/issues/96) |
| `CAND-GUARD`<br>大腿・脛 Guard の受け座 | 18 STL。[候補の保存先](audits/20260905-round2/guard-seat-candidates/)。 | 元支持殻の PLA 青/グレー相当だが、全案不採用。 局所 4 案と開放 2 案はいずれも挿入経路・可視面切除・分離体の問題で不採用。参照メッシュを含め全て印刷対象外。 [RV-16](https://github.com/hapx2yuki/Tachikoma/issues/97) |
| `CAND-EARLY`<br>初期の内部受け座比較 | 2 STL。 | 材質・向き・設定は未確定。 後続の Guard 受け座・全体干渉評価で採用されなかった比較形状。 [RV-16](https://github.com/hapx2yuki/Tachikoma/issues/97) |
| `REF-INTEGRATED-COXA`<br>本流へ統合した coxa 修正の比較保管 | 1 STL。 | 材質・向き・設定は未確定。 ポケット修正そのものは採用済み。製造は HW-coxa_bracket / HW-coxa_bracket_m の現 STL を参照し、この比較ファイルを追加部品として重複印刷しない。 [P-04](https://github.com/hapx2yuki/Tachikoma/issues/14) / [P-05](https://github.com/hapx2yuki/Tachikoma/issues/15) |
| `CAND-NO-CAD`<br>頭内サーボ配置・7 点の頭支持・手の接合 | 0 STL。 | 材質・向き・設定は未確定。 支持柱、受け座、手の接着部について、採用済みの新規印刷一式と本数はまだない。金属 M3 締結具を印刷部品に数えない。 [RV-09](https://github.com/hapx2yuki/Tachikoma/issues/90) / [RV-13](https://github.com/hapx2yuki/Tachikoma/issues/94) / [RV-17](https://github.com/hapx2yuki/Tachikoma/issues/98) |

## 現在の 3MF 全 27 件

**この表は現在ファイルの内容です。元のプレート計画とも、印刷済み数量とも区別します。** 形状/設定エラーは 9 件のプレートにあります。エラーがないプレートも部品の設計保留を解除しません。既存の 3MF は上書きせず、採用する現 STL と必要数だけを別名で配置してください。PETG_ 系と PETG_Walk_ 系は旧履歴であり、JSONの `current_print_first_required=false` として現行必要数・今印刷可数から除外します。PETGの旧プレートを現行候補へ足し戻しません。

| ID・3MF | 現在入っている部品と個数 | 不一致・注意 |
|---|---|---|
| PL-01<br>[TACHIKOMA_Phase0_PETG.3mf](../TACHIKOMA_Phase0_PETG.3mf) | tibia_link ×1 / femur_link ×1 | **形状/設定エラー**: SHAPE_REVIEW: tibia_link.stl distance=infmm volume=6.848% / SHAPE_REVIEW: femur_link.stl distance=7.596mm volume=2.097%。初期試作の旧 tibia・femur。現行骨格へそのまま使用しない。 警告: UNMANAGED_PLATE: 単発3MF。全数計画の数量とは照合しない |
| PL-02<br>[PETG_1_Chassis.3mf](../hardware/stl/PETG_1_Chassis.3mf) | audio_cradle_spk ×1 / chassis ×1 / eye_carrier ×2 / claw_mount ×1 / claw_mount_L ×1 | **形状/設定エラー**: SHAPE_REVIEW: chassis.stl distance=20.04mm volume=2.173%。形状・数量の一致は、この部品の組立成立や印刷済み在庫を証明しない。 |
| PL-03<br>[PETG_2_Tibia.3mf](../hardware/stl/PETG_2_Tibia.3mf) | pod_neck ×1 / tibia_link ×2 / tibia_link_m ×2 | 検査上の形状/設定エラーなし。標準 tibia 2＋鏡像 2＋pod_neck 1。Walk_3 と重複する。 |
| PL-04<br>[PETG_3_Femur.3mf](../hardware/stl/PETG_3_Femur.3mf) | femur_link ×2 / femur_link_m ×2 / battery_cradle ×1 | 検査上の形状/設定エラーなし。標準 femur 2＋鏡像 2＋battery 1。旧印刷済み Walk_1/2 と重複する。 |
| PL-05<br>[PETG_4_CoxaArm.3mf](../hardware/stl/PETG_4_CoxaArm.3mf) | shoulder_bracket ×1 / shoulder_bracket_L ×1 / forearm ×1 / forearm_L ×1 / camera_carrier ×1 / coxa_bracket ×2 / coxa_bracket_m ×2 / upper_arm ×1 / upper_arm_L ×1 | **形状/設定エラー**: SHAPE_REVIEW: shoulder_bracket.stl distance=7.376mm volume=2.194% / SHAPE_REVIEW: shoulder_bracket_L.stl distance=7.376mm volume=2.194% / SHAPE_REVIEW: forearm.stl distance=5.051mm volume=63.699% / SHAPE_REVIEW: forearm_L.stl distance=5.051mm volume=63.699% / SHAPE_REVIEW: coxa_bracket.stl distance=infmm volume=30.524% / SHAPE_REVIEW: coxa_bracket_m.stl distance=infmm volume=30.524%。形状・数量の一致は、この部品の組立成立や印刷済み在庫を証明しない。 |
| PL-06<br>[PETG_5_Mic.3mf](../hardware/stl/PETG_5_Mic.3mf) | audio_cradle_mic ×1 | 検査上の形状/設定エラーなし。0.12mm 層の単品。旧 Walk_1 の 0.2mm 層で嵌合できるなら追加不要。 |
| PL-07<br>[PETG_Walk_1_Chassis.3mf](../hardware/stl/PETG_Walk_1_Chassis.3mf) | battery_cradle ×1 / chassis ×1 / audio_cradle_mic ×1 | **形状/設定エラー**: SHAPE_REVIEW: chassis.stl distance=20.04mm volume=2.173%。形状・数量の一致は、この部品の組立成立や印刷済み在庫を証明しない。 |
| PL-08<br>[PETG_Walk_2_CoxaFemur.3mf](../hardware/stl/PETG_Walk_2_CoxaFemur.3mf) | femur_link ×2 / femur_link_m ×2 / coxa_bracket ×2 / coxa_bracket_m ×2 | **形状/設定エラー**: SHAPE_REVIEW: coxa_bracket.stl distance=infmm volume=30.524% / SHAPE_REVIEW: coxa_bracket_m.stl distance=infmm volume=30.524%。形状・数量の一致は、この部品の組立成立や印刷済み在庫を証明しない。 |
| PL-09<br>[PETG_Walk_3_Tibia.3mf](../hardware/stl/PETG_Walk_3_Tibia.3mf) | tibia_link ×2 / tibia_link_m ×2 | 検査上の形状/設定エラーなし。標準 2＋鏡像 2。PR-04 は別名の標準 1 個だけに分離し、L-02 後に残り標準 1＋鏡像 2。 |
| PL-10<br>[PETG_Walk_4_Rest.3mf](../hardware/stl/PETG_Walk_4_Rest.3mf) | camera_carrier ×1 / claw_mount ×1 / claw_mount_L ×1 / audio_cradle_spk ×1 / pod_neck ×1 / forearm_L ×1 / forearm ×1 / eye_carrier ×2 | **形状/設定エラー**: SHAPE_REVIEW: forearm_L.stl distance=5.051mm volume=63.699% / SHAPE_REVIEW: forearm.stl distance=5.051mm volume=63.699%。現物は 8 種 9 個。肩ブラケット左右・上腕左右の 4 個は入っていない。claw_mount_L は旧先行印刷と重複し得る。 警告: QUANTITY_REVIEW: 現物は全数生成定義と異なる。印刷済み除外/個別配置か履歴確認 |
| PL-11<br>[PLA_Black_1.3mf](../hardware/stl/PLA_Black_1.3mf) | Cabin_Front_Insert_Bottom_Wide_Black ×1 / Head_Insert_Black_x4 ×4 / Leg_Toe_Black_x12 ×12 / Arm_Left_Finger_Black_x3 ×6 / Cabin_Front_Insert_Bottom_Long_Black_x2 ×2 / Cabin_Front_Insert_Front_Black ×1 / Cabin_Front_Insert_Left_Black ×1 / Cabin_Front_Insert_Right_Black ×1 / Cabin_Front_Insert_Back_Black_x2 ×2 | 検査上の形状/設定エラーなし。トゥ 12＋指 6＋Insert 12＝30 個。指は同一メッシュの複製で鏡像指定がないため左右適合も RV-17 で確認。足・手・Cabin・Head の未解決設計を含む。黒を実フィラメントへ割当する。 |
| PL-12<br>[PLA_Matte_Blue_1.3mf](../hardware/stl/PLA_Matte_Blue_1.3mf) | shin_shell ×1 | 検査上の形状/設定エラーなし。現物は標準 shin_shell 1 個だけ。旧記録の Head_Top＋脛 4 個と異なる。 警告: QUANTITY_REVIEW: 現物は全数生成定義と異なる。印刷済み除外/個別配置か履歴確認 |
| PL-13<br>[PLA_Matte_Blue_2.3mf](../hardware/stl/PLA_Matte_Blue_2.3mf) | Head_Bottom_Armcut ×1 | **形状/設定エラー**: SHAPE_REVIEW: Head_Bottom_Armcut.stl distance=infmm volume=8.837%。現物は Head_Bottom 1 個だけ。Mouth_Neck と arm_pod 4 個は入っていない。 警告: QUANTITY_REVIEW: 現物は全数生成定義と異なる。印刷済み除外/個別配置か履歴確認 |
| PL-14<br>[PLA_Matte_Blue_3.3mf](../hardware/stl/PLA_Matte_Blue_3.3mf) | Cabin_Front_Blue ×1 | 検査上の形状/設定エラーなし。形状・数量の一致は、この部品の組立成立や印刷済み在庫を証明しない。 |
| PL-15<br>[PLA_Matte_Blue_4.3mf](../hardware/stl/PLA_Matte_Blue_4.3mf) | Cabin_Back_Blue_Repaired ×1 / Head_TailJoint_Blue_Optional_Cross ×1 / Leg_Thigh_Guard_Blue_x4 ×4 | 検査上の形状/設定エラーなし。形状・数量の一致は、この部品の組立成立や印刷済み在庫を証明しない。 |
| PL-16<br>[PLA_Matte_Blue_5_HeadTop.3mf](../hardware/stl/PLA_Matte_Blue_5_HeadTop.3mf) | Head_Top_Eyecut ×1 | 検査上の形状/設定エラーなし。形状・数量の一致は、この部品の組立成立や印刷済み在庫を証明しない。 |
| PL-17<br>[PLA_Matte_Gray.3mf](../hardware/stl/PLA_Matte_Gray.3mf) | thigh_cap ×4 / leg_foot_bored ×4 / Mouth_Cannon_Bored ×1 / Mouth_Ball_Bored ×1 | **形状/設定エラー**: SHAPE_REVIEW: Mouth_Cannon_Bored.stl distance=3.423mm volume=1.366%。形状・数量の一致は、この部品の組立成立や印刷済み在庫を証明しない。 |
| PL-18<br>[PLA_Matte_Gray_2.3mf](../hardware/stl/PLA_Matte_Gray_2.3mf) | Mouth_Cap_Grey ×1 / Leg_Shin_Guard_Grey_x4 ×4 / Head_TailJoint_Peg_Optional_Cross_Repaired ×1 / Mouth_Key_Grey ×1 / Arm_Left_Claw_Grey ×2 / Cabin_Turrent_Right_Grey ×1 / Arm_Right_Guard_Grey ×1 / Arm_Left_Guard_Grey ×1 / Head_Peg_Lower ×1 / Head_Peg_Upper ×1 / Head_TailJoint_Peg ×1 / Cabin_Turret_Peg_x2 ×2 / Cabin_Spinnarette_Grey_x4 ×4 / Mouth_Peg_Grey ×1 / Head_Dome_Grey ×1 / Head_Plug_Grey ×1 / Cabin_Turrent_Left_Grey ×1 / Head_Screw_Grey_x2 ×2 / Arm_Left_FingerTip_Grey_x3 ×6 / Cabin_Peg_x2 ×2 / Head_TailJoint_Ball_Grey_Optional_Cross ×1 | 検査上の形状/設定エラーなし。21 種 36 個。爪/指先は同一メッシュの複製で鏡像指定がないため、左右適合も RV-17 で確認。腕 Guard は Left 1＋Right 1。現モデルの Right 標準 1＋鏡像 1 と一致しない。手・脚 Guard・首・Head Insert 周辺は設計保留。 |
| PL-19<br>[PLA_Matte_White.3mf](../hardware/stl/PLA_Matte_White.3mf) | eye_pod ×2 / eye_pod_camera_shell ×1 / eye_pod_camera_base ×1 | 検査上の形状/設定エラーなし。形状・数量の一致は、この部品の組立成立や印刷済み在庫を証明しない。 |
| PL-20<br>[PLA_Matte_White_2.3mf](../hardware/stl/PLA_Matte_White_2.3mf) | Cabin_Eye_White ×1 | 検査上の形状/設定エラーなし。形状・数量の一致は、この部品の組立成立や印刷済み在庫を証明しない。 |
| PL-21<br>[PLA_Matte_White_3_CamBase.3mf](../hardware/stl/PLA_Matte_White_3_CamBase.3mf) | eye_pod_camera_base ×1 | 検査上の形状/設定エラーなし。現 STL との形状一致は現物カメラとの適合証明ではない。P-07/H-02 後に必要なら 1 個だけ。 |
| PL-22<br>[PLA_Red_1.3mf](../hardware/stl/PLA_Red_1.3mf) | Cabin_RedLight_Large_Red_x4 ×4 / Cabin_RedLight_Small_Red_x4 ×4 | 検査上の形状/設定エラーなし。大 4＋小 4。大ランプ右後の Cabin 交差を含む。赤を実フィラメントへ割当する。 |
| PL-23<br>[claw_mount_L.3mf](../hardware/stl/claw_mount_L.3mf) | forearm_L ×1 / forearm ×1 / claw_mount_L ×1 / elbow_shell ×1 / elbow_shell_L ×1 / upper_arm_L ×1 / upper_arm ×1 / shoulder_bracket_L ×1 / shoulder_bracket ×1 | **形状/設定エラー**: SHAPE_REVIEW: forearm_L.stl distance=5.051mm volume=63.699% / SHAPE_REVIEW: forearm.stl distance=5.051mm volume=63.699% / SHAPE_REVIEW: shoulder_bracket_L.stl distance=7.376mm volume=2.194% / SHAPE_REVIEW: shoulder_bracket.stl distance=7.376mm volume=2.194%。名前は単品でも 9 個入り。PETG 7 個は壁 2/15% で指定の壁 4/40% を満たさない。肩・前腕も旧形状。 警告: PRINT_SETTINGS_REVIEW: forearm_L.stl 壁/充填が生成定義未満 / PRINT_SETTINGS_REVIEW: forearm.stl 壁/充填が生成定義未満 / PRINT_SETTINGS_REVIEW: claw_mount_L.stl 壁/充填が生成定義未満 / PRINT_SETTINGS_REVIEW: upper_arm_L.stl 壁/充填が生成定義未満 / PRINT_SETTINGS_REVIEW: upper_arm.stl 壁/充填が生成定義未満 / PRINT_SETTINGS_REVIEW: shoulder_bracket_L.stl 壁/充填が生成定義未満 / PRINT_SETTINGS_REVIEW: shoulder_bracket.stl 壁/充填が生成定義未満 / UNMANAGED_PLATE: 単発3MF。全数計画の数量とは照合しない |
| PL-24<br>[elbow_shells_PLA_Matte.3mf](../hardware/stl/elbow_shells_PLA_Matte.3mf) | elbow_shell ×1 / elbow_shell_L ×1 | 検査上の形状/設定エラーなし。中心位置の差だけで形状一致。既印刷品を向き・取付位置修正で使えるか確認する。 |
| PL-25<br>[eye_pod_camera_base_x2.3mf](../hardware/stl/eye_pod_camera_base_x2.3mf) | eye_pod_camera_base ×2 | 検査上の形状/設定エラーなし。予備 2 個のプレート。機体の必要数は base 1 個であり、追加 2 個を指示しない。 警告: UNMANAGED_PLATE: 単発3MF。全数計画の数量とは照合しない |
| PL-26<br>[foot_pad.3mf](../hardware/stl/foot_pad.3mf) | foot_pad ×1 | 検査上の形状/設定エラーなし。1 個だけ。計画 4 個・旧印刷報告 4 個とは別の値。TPU 95A を維持する。 警告: QUANTITY_REVIEW: 現物は全数生成定義と異なる。印刷済み除外/個別配置か履歴確認 |
| PL-27<br>[leg_foot_bored.3mf](../hardware/stl/leg_foot_bored.3mf) | leg_foot_bored ×1 / Arm_Left_Claw_Grey ×1 | 検査上の形状/設定エラーなし。足 1＋元爪ハブ 1。ファイルの存在から爪が印刷済みとは判断しない。 警告: UNMANAGED_PLATE: 単発3MF。全数計画の数量とは照合しない |

**現 27 プレートに Mouth_Neck_Bored と arm_pod の 4 変種は入っていません。** 旧 Blue_2 の印刷報告は残しますが、不足した場合は現 STL から個別に配置が必要です。黒・赤のプレートは物理フィラメントの割当を必ず変更し、TPU は TPU のまま扱います。

## 根拠と更新方法

- [変更された部品の製造上の意味](audits/20260905-round2/manufacturing.md)と [形状差・SHA-256](audits/20260905-round2/manufacturing-diff.json)。
- [現 27 プレートの機械検査結果](audits/20260905-round2/final-geometry/verify/check_print_artifacts.json)。部品ごとの実収録数、形状差、材質、壁、充填率を参照。
- [旧印刷記録 P-02](https://github.com/hapx2yuki/Tachikoma/issues/12)、[再使用判断 P-05](https://github.com/hapx2yuki/Tachikoma/issues/15)、[9/4 camera base の版差 PR-10](https://github.com/hapx2yuki/Tachikoma/issues/79)。本文は更新され得るため、旧記録の転記内容は本書の JSON にも保持。
- [全数表](print_manifest.md)、[印刷設定](printing.md)、[組立手順](assembly.md)、[固定部品同士の未解決干渉](audits/20260905-round2/static-assembly.md)。過去の「全合格」「一式即印刷」は今回の部品別保留を上書きしない。

現物確認時は JSON の current_usable_qty に確認した数、stock_verified_at に日付、stock_verification_evidence へ写真・版の根拠を追記し、additional_qty を再計算します。試験で使用する 1 個は設計必要数の内数です。破壊試験片や予備を追加する場合だけ、その用途と個数を別行で足します。追加購入・追加印刷・設計保留の区別を保ち、Issue には対象部品 ID と試験結果を記録してください。

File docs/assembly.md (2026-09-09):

# 組立手順 (脚 1 本 → ベンチ試験 → 全体 → 腕) — 2026-09-05 監査・購入照合反映版

**2026-09-05 第2次監査:** この手順の旧合格記録は製作許可を意味しない。現在は足の嵌合/支持、頭内収納と固定、ポッド梁に未解決項目がある。
先に[最新監査](audits/20260905-round2/README.md)、[印刷優先構成の現在地](print-first.md)、[追加購入一覧](additional-purchases.md)、[部品別の印刷・再使用条件](additional-printing.md)を確認する。既存3MFは保存してあり、修正済みSTLとの不一致を含む。各工程の着手条件は[全107課題の見直し](issues-audit-20260905.md)を優先する。

関節は全て**ホーン片持ち結合** (アイドラーネジは廃止)。脚サーボの寸法基準は旧
DS3218 級（履歴上のフットプリント、出力軸デュアルベアリング必須）であり、現行
print-firstのLD-220MG候補を適合済みとは扱わない。腕は MG90S ×3/腕 (肩ヨー/肩ピッチ/肘。
2026-07-29 固定爪化でグリップ用サブマイクロは腕から廃止済み — §2.5 参照)、
目はサブマイクロ ×2 (左右キョロキョロ, §2.7)。

**ガード・固定爪の接着前に必要な改訂:** 大腿/脛ガードは体積の81%/78%が支持殻に埋まり、26方向の候補でも受け座へ挿入できなかった（RV-16）。固定爪は指・指飾りを含む36組中10組に交差があり、公差/圧入仕様が未確認（RV-17）。下記の古いembed率と「現物合わせ」は組立成立の根拠にならない。

## 0. 事前準備

**タッピングねじの扱い (全工程共通)**: M3×10 / M2.6×8 / M2×8 / M1.7 のセルフタップは
印刷ボス (PETG/PLA, 下穴 φ2.8/φ2.2/φ1.6/φ1.1) へ直接ねじ込む。**低速・低トルクで、
手応えが急に軽くなったら (空転/白化) 増し締めせず一旦抜いて入れ直す**。締めすぎると
ボスが割れる (肉厚は `check_screw_bosses.py` で 70% 以上を保証しているが、トルク超過には
耐えない)。電動ドライバは使わない。同じ穴への抜き差しは 3 回までを目安に。
膝/股/ヨーホーンの共締め M2.6 は下穴 φ2.2 (`HORN_PILOT_D`, 2026-09-04 に 2.0→2.2。印刷済み
coxa/femur の旧品は P-05 で版・残肉を確認してから加工判断。coxa は穴径以外にも今回の形状差がある)。tibia 側は外側増厚部を貫通して 6mm 掛かる。M3×10 は皿頭であり、なべ頭を前提にしたタブ座へ適合するとは限らない。頭形も P-01/P-03 で照合する。

1. サーボとホーンをノギスで実測 → `hardware/src/config.py` の
   [要実測] 値 (STD / MICRO / SUBMICRO プロファイルと HORN_*) を更新
2. `cd hardware/src && ../../.venv/bin/python build_all.py` で STL 再生成。
   **`Head_Top_Eyecut.stl` はこのコマンドの対象外** (独立スクリプト) —
   `EYE_BORE_D`/`EYE_SOCKETS_150` 等の目ソケット関連値を変更した場合は
   リポジトリルートから `.venv/bin/python tools/make_head_eyecut.py` も
   別途実行して再生成すること (`docs/print_manifest.md` 参照)
3. `AGENTS.md`記載の全検証と`docs/audits/20260905-round2/`の追加検証を再実行する。
   旧7本だけでは、組立挿入経路、部品同士の自己干渉、実際の足底接触を検出できなかった。
4. 既存良品を P-02/P-05 で照合し、FL標準の不足部品だけ試作する。PR-04 の tibia 1 本→L-01/L-02 の片脚試験→PR-11 の残数の順。現 foot_pad は支持不成立のため同形追加を止め、RV-06 で採用形状を確定する。

## 1. 脚 1 本の組立 (Go/No-Go 判定)

1. **サーボを1個ずつ校正する**: P-03 で現品の許容電圧・パルス範囲を確認し、リンクを外した1個だけ接続する。`CALIBRATION_MODE` は使用対象20軸へ1500µsを出すが、予備のch12は停止している。`/cal?us=...` で1500µsから小刻みに範囲を広げ、角度・電流・振動を記録する。未知の個体へ500/2500µsを直接指示しない。500–2500µs=180°は現firmwareの換算仮定であり、メーカー仕様や実測の代わりにはならない。対象サーボ、2銘柄のMG90S、ES9251IIを区別し、機械端へ押し続けない。異なる角度特性は個体別の変換を設計・検証する。`DEG_RANGE` は全軸共通なので、1個に合わせた変更を混在系へ適用しない。
2. 膝サーボを femur_link の箱枠へ +Y 側から挿入、**M3×10 タッピング×4** で
   タブ固定 (ケース底が -Y 側へ突き出るのは仕様。装飾ガードで隠れる)
3. 股ピッチサーボを coxa_bracket の箱枠へ挿入、同様にタブ固定
4. tibia_link の円板ポケットに付属ホーンを埋め、M2.6 タッピングで共締め
   → ホーンをサーボ軸へ (tibia 鉛直下向き = 中立、中心ビスで固定)
5. femur を同様に股ピッチサーボへ (femur 水平 = 中立)
6. leg_foot_bored のソケット・保持を1脚分で検品する。現 foot_pad は全装備で先行接地できないため、旧手順のまま最終接着しない。RV-06 の支持案確定後に1脚で試験する。トゥなしの片脚保持試験と、全装備の床支持試験を分ける。
7. **ベンチ試験**: coxa をバイスで水平固定し、
   - スイープ動作で干渉・ガタ・ホーン緩みを確認
   - **股ピッチ軸から足先まで水平 155mm** の姿勢 (股ピッチ約 -20°/膝約 +15°) で足先に
     **1.2kg の錘** → 股ピッチ = 1.2×15.5 ≈ **18.6 kgf·cm** を 10 秒保持できること (P-03で現品の6V対応を確認した場合の6V試験点、
     脱調・振動・ホーン滑りなし)。これは2026-09-04のホスト計算に使った試験条件で、
     `sim_gait.py` [3] の全域最悪 18.5 kgf·cm
     (総重量 3.0kg・実重心 y=-39mm・3/4 点支持静力学, 2026-09-04) と同等の負荷。旧記載
     「1.2kg (40% 負担)」はレバー未指定で試験として不定だった
   - 上の最大負荷は、無負荷・軽い負荷から段階的に増やして到達する試験点。
     保持不能、振動、ホーン滑り、急な電流増大があれば直ちに負荷を下ろす。
     10秒の成功だけで連続運転可能とは判定せず、想定歩行時間の温度・電圧降下もL-02/L-11へ記録する。
   - 保持電流を測定する。旧記載の「期待1.5〜2.2A」「1.5A未満」は未実測で互いに矛盾していたため撤回。
     DS3218メーカー値は5Vでストール1.8A、6.8Vで2.2Aという旧比較値であり、現行候補へ
     流用しない。6Vの実力・連続保持能力は対象個体で実測する。**未確認品へ7.4Vを加える
     旧案はNo-Goで、昇圧を対策に使わない**。
   - 膝ネック増厚部 (tibia 外側 +3mm) に白化・割れなし。装飾トゥを付けた状態なら極端姿勢で
     トゥ先端が foot_pad より先に机へ触れないか観察 (S-04)
   - 電流測定器は定格と許容時間を確認する。SANWA PM7aには電流測定機能がない。
   → **持ち上がらなければ全印刷へ進まない**。型番・試験電圧・レバー長・錘・保持時間・電流・温度を保存する。

メーカーの定格は[DS3218データシート](https://www.dsservo.com/down.asp?id=22)で確認した
2026-09-05時点の履歴資料であり、現行サーボの合格根拠ではない。旧比較候補LD20MGと、
現行print-firstのLD-220MG候補は別製品のため、DS3218の値を流用しない。LD-220の寸法・
トルク・電流は実測前No-Goとする。
USBを使う中立化・書込みは、先にDevKitCへの外部5V線を切り離す (`wiring.md`「USB接続時の給電」)。
本体の通常起動は脱力から「立つ」の明示操作で行い、順次通電が終わるまで支持台で支える。

## 2. シャーシと残り 3 脚

1. ヨーサーボ×4 をシャーシ上面から挿入 (ケース長手は 4 個とも **X 軸平行・
   ボディ中央向き** — v3 はケース向きが脚方位と独立)。タブは**台座ボス
   (高さ3mm) に着座**、M3×10 で固定。ギヤヘッドはプレート下面へ突き出る
2. ヨーホーンを coxa 天板ポケットへ埋めて M2.6 共締め → 各脚を中立姿勢
   でサーボ軸へ固定。**v3 の脚方位は非均等**: FR 15° / FL 165° / RL 210° /
   RR 330° (正面=90°。前脚は正面から±75°、後脚は±120°)。**FR と RL には
   ミラー版パーツ (`_m`) を使う** — 取り違えると 45° ペアの股ピッチサーボ
   同士が干渉して組めない
3. **ポッドネック**: RV-15 の首/Cabin全接合と RV-07 の印刷強度を確定してから S-01 で取り付ける。現梁と TailJoint の交差は未解決なので、旧手順の被せ接着を先行しない。
4. **頭無しの仮電装（L-06）**: PCA board0=0x40は脚12軸、board1=0x41は腕6軸＋目2軸。ch12は予約・常時停止。PCA2枚セットは現物確認前なので、先に実物を確認する。旧中央スタック（M2.5×16 M-F×4＋M2.5×6×4）は設計基準であり、頭内の収納成立を意味しない。H-06のCabin電装室とRV-09のケース配置は未確定で、現シャーシへ全基板を最終固定しない。
   頭無しの試験では、可動部と接触しない脱着可能な仮保持、絶縁、配線の引張止めを確認する。基板の表裏・実寸・端子・挿抜空間は実物で照合する。M2.5のねじセットは必要な長さとねじ種別を確認し、不足と推測して重複手配しない。
   バッテリーは既存 battery_cradle とベルクロを先に照合し、電池寸法・保持・着脱経路を確認する。最終の電装収納は H-06、頭支持は RV-13 が成立した版で行う。
5. 配線は wiring.md 厳守 (**サーボ電源は PCA9685 を経由させない**)
6. 通電順: サーボ未接続で、現物の許容入力と出力設定を確認し電圧を測る。6V設定は接続する全個体の6V適合をP-03で確認した場合だけ使う。1個→頭無し試験で必要な脚12個へ段階的に増やし、支持台・独立停止手段・電流・温度を確認する。腕6個と目2個の本体取付を前倒ししない。電池入力と各出力バスの電流を別々にEL-09へ記録する。

## 2.5 腕の組立 (脚のベンチ試験合格後でよい)

腕単体のベンチ組立は脚と並行できる。本体への取付は実脚配置とRV-09/RV-10の収納・干渉確認後にA-03で行う。腕の重量と接地・干渉が歩行へ与える影響は別に検証する。
**手は 2026-07-29 にキット準拠の固定爪へ変更済み (可動グリッパは廃止)** —
サーボ・配線を持たない受動パーツなので、調整項目は claw_mount と爪ハブの
接着面だけでなく、RV-17の指・指飾りを含む嵌合公差と挿入経路を確認する。

1. **肩ヨー**: MG90S をシャーシの腕マウント開口 (2026-07-28 実ソケット移設:
   Head_Bottom_Blue 側面ソケット直下, 正面から左右 ±40°, `C.ARM_MOUNT_XY`)
   へ**上から挿入・軸下向き** (脚ヨーと同じ要領)。タブを台座ボスに着座させ
   M2×8 タッピング×2 で固定。ギヤヘッドとホーンはプレート下面側へ出る
2. **肩ブラケット**: サーボ中立 (1500µs) の状態で、shoulder_bracket **上面**の
   ホーンポケットに付属ホーンを埋めて M2.6 共締め → ヨーサーボ軸へ吊り下げ
   (**腕は正面向きでなく放射外向き (正面から40°) = 中立** — 実機ソケットの
   向きに合わせる。組付け時、上腕が Head_Bottom ソケットの開口方向を向く
   ことを目視で確認する)。肩ピッチ用 MG90S をブラケットへタブ固定
3. **上腕**: upper_arm のホーン円板を肩ピッチサーボへ (腕鉛直下向き =
   ピッチ 85° 付近)。肘用 MG90S を upper_arm の箱枠へタブ固定
4. **前腕**: forearm のホーン円板を肘サーボへ (伸ばし = 肘 0°)。
   2026-07-29 固定爪化で FOREARM_LEN 24→16mm に短縮済み
5. **手 (固定爪, キット準拠 — 2026-07-29 可動グリッパから変更)**:
   - claw_mount (PETG, forearm と同色) の背面を forearm の手首面 (平坦端)
     へ接着 [現物合わせ, 瞬間接着剤またはエポキシ]。可動部・配線は無し
   - **Arm_Left_Claw_Grey** (爪ハブ, 150% 印刷 ×2, **両腕とも Left 版を
     使用** — Arm_Right_Claw_Grey は形状が異なる別パーツなので使わない)
     の平坦近位面 (接着面を #400 で軽く粗面化し**エポキシ**推奨 — 瞬着より靱性が高い, 2026-09-04 M-03)を claw_mount 前面へ突き合わせ接着 [現物合わせ, 軽く
     均してから接着]
   - **Arm_Left_Finger_Black_x3** (指, 150% 印刷 ×6 = 3本×2腕, **元キット
     タロン形状のまま無加工**) を爪ハブの 3 本のペグへそれぞれ差込 (圧入+
     接着併用)
   - **Arm_Left_FingerTip_Grey_x3** (指先チップ, 150% 印刷 ×6) を各指の
     根元 (ペグとの接合部, キットの組立方法どおり) へ接着
6. **腕シェル (元キットパーツの被せ)**:
   - arm_pod_upper / arm_pod_lower (元 Arm ポッドのクラムシェル 2 分割) を
     upper_arm を上下から挟むように被せて接着 (ホットボンド推奨=脱着可)。
     肘側下面の大きな開口は**肘窩** (前腕折り畳みの掃引域) なので塞がない。
     上殻ホーン側フランクの小さな開口 (~18×5mm) は骨格ウェブの逃げ
     (元ポッドのリブと同位置) — 気になる場合は Arm_Left/Right_Guard_Grey の
     接着位置で隠す
   - elbow_shell (元 Elbow 球の半殻) は改訂STLの位置で肘サーボのケース底へ合わせる。
     原球中心は肘軸から局所Y=-13.8mm。旧原点配置ではケースへ食い込む。
     欠き底は原球中心から-6mmで、ケース底との設計隙間は0.3mm。接着保持力は現物確認
   - Arm_Left_Guard_Grey / Arm_Right_Guard_Grey (左右別形状の元パーツ,
     各 1, 150% 印刷) をそれぞれの腕のポッド表面へ接着 (任意,
     位置は元キット説明書/実機写真と現物合わせ)
7. **左腕**: *_L パーツで同様に (機構は左右ミラー。ファームがヨーを反転)
8. **ベンチ確認**: `/arm?pose=tuck` → `ready` → `reach` → `wave` を
   順に実行し、各姿勢で干渉・脱調がないこと。爪は固定 (可動なし) — 接着が
   しっかり効いて指がぐらつかないことを確認する
9. **腕可動域の実機確認 (重要)**: 検証は粗近似モデルによる。
   **脚を静止 (立位) にしたまま**腕の全域 (特にヨー ±15° 端 × 脚ヨー大) を
   低速で試し、前脚・coxa とのクリアランスを目視確認してから歩行と併用する

## 2.7 目ポッド (キョロキョロ機構) ×2 (左右)

2026-07-28 設計変更: 中央目は固定カメラ目に置換された (§2.9 参照) ため、
本節は**左右 2 目のみ**を扱う (元キット STL の 3 ソケットのうち中央
(EYE_SOCKETS_150[1]) を除く 2 つ)。

1. **eye_pod のドット穴 3 つを黒く仕上げる** (元キットの目パーツと同じ
   モールド穴。黒塗料の流し込み or 黒フィラメント片の接着。このドット群が
   視線マークになる)
2. サブマイクロサーボを eye_carrier のポケットへ (付属ビス)
3. **ホーンを先に eye_pod へ共締めする**: ポッドを手に持ち、背面ポケットに
   ホーンを埋めて、ホーンのアーム穴 2 個から極小タッピング (BOM #29,
   付属ビス流用可) を下穴へ締める。**ホーン中心ビスは使わない** (ポッドに
   塞がれて締結できない。目は無負荷なので摩擦保持で足りる)。ホーン実穴と
   下穴が合わない場合はホーン穴経由で φ1.2 ドリルで現物開け直し
4. **サーボ中立 (1500µs) でドット群がほぼ真下を向く**スプライン位相を選び、
   眼球+ホーンをサーボ軸へ押し込む (ドット群はキャップ軸から ~45° 偏心して
   おり、サーボが回ると視線が泳ぐ)。位相の残差は Web UI の目トリム (±200µs
   ≈ ±18°) で吸収。抜けが心配なら軸に微量の瞬間接着剤
5. **シェル内側から**眼球のネックを Head_Top の目ソケットのボアへ通し、
   carrier をシェル内側へ接着 [現物合わせ]。前提: Head_Top は
   `hardware/stl/Head_Top_Eyecut.stl` (ソケット底へ **φ30 貫通ボア**加工済み)
   を印刷しておく (printing.md。元の Head_Top はソケット底が塞がっている)。
   キャップ (φ37.7 = 元キットの目パーツと同形状) は座グリ (φ42.3) の中で
   回転し、縁との隙間は片側 ~2.3mm。**キャップ底を座グリ床から ~1.5mm
   浮かせる** (check_eye [5] と同じスタック)。全回転で床・縁に擦らないこと
   を確認
6. **carrier のロール向き**: 3 つのソケット法線は仰角 ~47° で頭部中心下方へ
   収束するため、サーボの尻尾と中央目の camera_carrier が中心付近で近づく。
   **サーボケースの長辺を水平の接線方向** (右目・左目 = 前後方向) に向けて
   接着すること — この向きで左右サーボ尾部間クリアランス 41.9mm、中央
   カメラとの間も 22.6mm 以上を確保 (check_eye [5] で検算)。サーボ線は
   ケース後端から接線方向へ出るので、そのまま横へ逃がしてシャーシ 7 タブ
   間隙間 (`docs/wiring.md` 参照) から胴へ下ろす
7. WS2812 の LED 1・3 (右目・左目) を carrier 裏へ貼ると眼球がバックライト
   される (任意。中央 LED (ch2) は中央目がカメラ化されたため未使用/割愛可)
8. `/eye?mode=kyoro` でキョロキョロ / `front` で正面固定 / `scan` で掃引
   (いずれも左右 2 目のみ動作。中央固定カメラは §2.9 参照)

## 2.8 音声会話ユニット (砲身内蔵マイク+スピーカー)

`docs/voice.md` の音声会話 (STT→LLM→TTS ブリッジ) 用。配線は
`docs/wiring.md` の「音声ユニット (I2S) 配線」参照。**前提パーツ**
(いずれも `hardware/stl/` に出力済み。`make_audio.py` 生成):
`audio_cradle_mic` (INMP441 保持円筒。回転キー突起付き) /
`audio_cradle_spk` (スピーカー抜け止めワッシャ) /
`Mouth_Cannon_Bored`・`Mouth_Neck_Bored`・`Mouth_Ball_Bored` (元パーツの
内部をボーリング加工した版。**鉄則1 に従い外観は元パーツのまま**、
`Head_Top_Eyecut.stl` と同様に隠れる内部だけ加工)。

**印刷前に実物を実測すること**: INMP441 基板寸法 (設計仮定 14×11×3mm) と
スピーカー厚 (仮定 5mm) は市販品でばらつく。実測が `config.py` の
`AUDIO_MIC_*` / `AUDIO_SPK_REAL_H` と違う場合は更新 → `build_all.py`
再生成 → `check_audio.py` 緑を確認してから印刷する。

1. **INMP441 を audio_cradle_mic へ固定**: cradle 中央のトレイへ基板を
   差し込み瞬着で軽く固定する。マイクの音孔は cradle の φ1.8 ポート穴
   (キー突起の反対側) に合わせる
2. **audio_cradle_mic を砲身奥のマイクポケットへ圧入**: 配線 (マイク6芯)
   を砲身中心ボア方向へ引き出しながら、**キー突起をポケットのキー溝に
   合わせて**押し込む。キーが噛み合わない向きでは物理的に入らないので、
   入らないときは回して合わせる (正しい向きでマイクポートが砲身下面の
   φ1.8 開口と一致する)
3. **φ20mm スピーカーを砲口側から挿入**: 振動板面を砲身の開口 (元キットの
   発射口モールド) へ向け、配線 (2芯) を後方へ引き出す
4. **audio_cradle_spk (抜け止めワッシャ) をその奥へ押し込む**: スピーカー
   の脱落を防止する (現物合わせでホットボンド併用可)。**外観は元の
   Mouth_Cannon_Grey と同一** (加工は内部のみ)
5. **配線の引き出し経路**: 計8芯 (マイク6+スピーカー2, AWG30, BOM #33) を
   Mouth_Cannon 後端 → Mouth_Neck_Bored のボア →
   Mouth_Ball_Bored (Head_Bottom 前面ソケットに嵌るボール) のボア →
   **Head_Bottom_Armcut のマウス配線受け穴 (2026-07-30 焼き込み, φ7mm — 旧
   「Head_Bottom 側は現物合わせ」を置換, `docs/printing.md` 「音声内蔵」参照)**
   → 頭部内部キャビティ → MAX98357A (頭部/シャーシ側搭載, 配線は
   wiring.md 参照)。既存の Mouth 組立 (Cap/Neck/Ball/Key/Peg, キット標準
   組立) の嵌合を崩さないよう、配線が可動部 (Ball ジョイントの回転軸)
   を横切らないルートを現物合わせで選ぶ (この区間のみ現物合わせ — Ball
   自体は回転しない接着継手だが、配線がボア内で弛まないように取り回す
   という意味の現物合わせで、穴あけそのものは不要になった)
6. **Mouth 一式の組付け**: Mouth_Cap_Grey で砲身外套を被せ、既存の
   Mouth_Key_Grey / Mouth_Peg_Grey で固定するキット標準の組立を維持する
   (音声ユニット内蔵によって外側の組立手順は変わらない)。**Ball→Neck→
   Cannon の物理チェーンと露出量 (2026-07-30 実測再構成、同日中に QA で
   さらに修正)**: Ball (`Mouth_Ball_Grey`, 実測球径φ25.1mm) が Head_Bottom
   前面ソケット (実測φ26.8mm, `config.py` MOUTH_SOCKET_*) にスナップ嵌合し、
   Neck (`Mouth_Neck_Blue`, 実測全長16.09mm) が Ball と Cannon 後端ソケット
   (実測φ10.7mm) を現物合わせで継ぐ — Cannon 後端はソケット面から軸方向
   20.0mm、砲口は同61.8mm の位置に出る (Cannon 全長41.8mmは REAR から丸ごと
   頭部外)。この露出量は `hardware/src/config.py` の MOUTH_CANNON_T /
   MOUTH_CANNON_TIP_T / MOUTH_CANNON_REAR_STANDOFF_MM として一元管理され、
   `tools/make_visuals.py` の描画と `tools/check_arm.py` [8]/[8b] (腕との
   干渉ゼロ・「両腕の間に見える」というレイアウト意図の両方) が同じ値を参照
   する。**QA修正の経緯**: 当初 (Ball 球心が Neck flange 面と一致する
   「coincident」読み, standoff=16.1mm) は Ball と Neck の manifold3d
   交差体積が Neck 自身の体積の 84.6% に達し、Neck がほぼ全体 Ball に埋没
   することが判明した。物理的に完全非干渉な配置 (standoff=28.6mm) は
   `check_arm.py` [8b] の「両腕の間に見える」レイアウト意図を破るため、
   両者を両立できる範囲で妥協した standoff=20.0mm を採用している (交差体積は
   Neck 体積の49.4%まで低減、完全解消はしていない — 詳細は
   `hardware/src/config.py` MOUTH_CANNON_REAR_STANDOFF_MM のコメント参照)。
   Mouth_Neck_Blue (青) と Mouth_Ball_Grey は完成後も外から視認できる位置に
   あるため、この2部品も **意匠パーツとして通常どおり塗装・組付け**
   すること (キット説明書の「隠れて見えない」という従来の想定は誤りだった
   — 詳細根拠は `tools/data/kit_assembly_front.json` の該当エントリ参照)。
   ただし Mouth_Neck_Blue は上記の通り体積の半分近くが Ball の陰に隠れる
   配置になっているため、完成写真ほどくっきり全周が見えるとは限らない点に
   留意すること (UNVERIFIED: ピクセル単位の写真照合はしていない)。

   **ポーズ角 (2026-07-31 更新)**: Ball→Neck→Cannon 一式を頭部ソケットへ
   接着する際の向き (`MOUTH_CANNON_ROT_X_DEG`) は、旧版 (-60.38°, ソケット
   開口の実測外向き法線をそのまま採用=水平から60.4°下向き) からユーザー
   提示の実物完成フィギュア写真 (「ほぼ前方・わずかに下向き、60°下向きでは
   ない」) に基づき **-18.0° (水平から18°下向き)** へ変更した。Ball の中心
   (頭部ソケットに固定) を回転ピボットとしてポーズだけを振る変更であり、
   Ball/Neck/Cannon 自体の形状・接着面・standoff (20.0mm) は不変。新ポーズで
   Mouth_Neck_Blue がソケット開口リムとわずかに干渉する (実測0.056cm³)ため、
   `Head_Bottom_Armcut` のソケット内縁に不可視の逃がしカット
   (`hardware/src/make_head.py` `_mouth_socket_relief_chassis()`) を追加
   焼き込み済み — 外から見える開口径 (φ26.8) 自体は変更していない。
   `tools/check_arm.py` [8]/[8b] は新ポーズでも PASS (むしろ [8b] のレイアウト
   マージンは +1.5mm→+17.4mm へ改善)。根拠画像・実測値は
   `hardware/src/config.py` の `MOUTH_CANNON_ROT_X_DEG` 直上コメント参照。
7. **通電確認**: `tools/voice_bridge.py --mock` でブリッジを起動し、
   実機の PTT 操作でマイク音声が届く/スピーカーから 440Hz トーンが鳴る
   ことを確認してから、実 API キーでの本番運用に切り替える

## 2.9 頭部中央目カメラ (固定, 左右目はキョロキョロのまま)

`docs/voice.md` §5「カメラ連携」用。**2026-07-28 設計変更**: カメラは
ポッド (Cabin) のメインアイではなく、**頭部の中央可動目を固定カメラ目
(`eye_pod_camera`) に置換したもの**へ内蔵する。左右 2 目はキョロキョロ
(§2.7) のまま。ポッドのメインアイ (`Cabin_Eye_White`) は元パーツのまま
無加工で使う (Cabin 前面の組立はキット標準手順のみでよい)。

**撤去理由 [実測済]**: ポッド前面のメインアイ位置は前方視界の約 80% が
自機体 (シャーシ下面/クレードル) に遮蔽されることが `robot_meshes
(dress=True)` 全アセンブリのレイキャスト検証で判明した。頭部中央目は
シャーシから離れているためこの問題が無い (`tools/check_camera.py` [4] が
恒久チェックする)。

配線は `docs/wiring.md` の「カメラ電源配線」参照。**前提パーツ** (いずれも
`hardware/stl/` に出力済み。`make_camera.py` 生成): `eye_pod_camera_shell` +
`eye_pod_camera_base` (印刷用 2 分割, 2026-08-19 印刷性再設計 — 一体版
`eye_pod_camera` は印刷失敗多発のため分割した。一体版 STL は検証/可視化用
参照形状で印刷しない。形状は元キットの目パーツ Head_Eye_White のまま、
キャップ軸から 38.0° 偏心した位置に瞳ボア φ10mm + モジュール収容キャビティ
を追加加工) / `camera_carrier` (レンズ側の子基板を保持する隠しパーツ。
2026-08-19 短縮 — base のポケットへ先入れする方式になり、旧設計の頭部
シェル接着ウィングは廃止)。加工域以外は元メッシュのまま (鉄則1,
`tools/check_camera.py` [1] で確認済み。分割の整合は同 [5])。

**光軸の向き (重要)**: 中央目ソケットの法線は仰角 ~46.6° (ほぼ真上向き) —
既存のキョロキョロ機構と同じ「ドット群が軸から偏心する」原理を使い、
瞳をキャップ軸から 38.0° 偏心させた位置に開けている。**この偏心方向が
正しい向きでグルーされて初めて光軸が水平前方 (残差 ~8.6°) になる** ため、
取付時の回転位相 (下記手順3) を必ず守ること。完全な水平相殺 (46.6°)は
Head_Eye_White カップの材が薄く、モジュールを収めるだけの肉厚安全代が
取れないため断念した (`config.py` CAM2_THETA_DEG コメント参照)。

**印刷前の検証**: 寸法は BOM #34 のモジュール実寸 (子基板 20.5×12.5×5.54mm)
前提で設計済み。別モジュール (例: BOM #34b の ESP32-CAM は基板一体型で
寸法が大きく異なる) を使う場合や実測が違う場合は `config.py` の
`CAM2_MODULE_*` を更新 → `build_all.py` 再生成 → `check_camera.py` 緑を
確認してから印刷する。

1. **カメラモジュール (レンズ側の子基板) を camera_carrier へ固定**:
   ポケットへ子基板を差し込み、瞬着で軽く固定する (ポケットは実寸+片側
   0.4mm クリアランスの設計)
2. **配線を側方の切り欠きから引き出す**: 電源 (VCC/GND) の AWG30
   シリコン線 2 芯を camera_carrier 側方の配線切り欠きから外へ引き出す
3. **carrier+モジュールを eye_pod_camera_base のポケットへ先入れし、
   shell を被せて接着する (2026-08-19 分割版)**: carrier を base の斜め
   ポケットへ落とし込み (ポケット形状で挿入向きが機械的に一意に決まる —
   誤った回転では入らない)、FPC を base 底面のスロットから引き出す。
   次に eye_pod_camera_shell を上から被せ、base 上面のリングプラグを
   shell 底面の溝へ嵌合させて接着する — 斜めチャネルが carrier を貫く
   ため shell/base の回転位相も一意。光軸仰角の残差 8.6° は要求 ±10° に対し余裕 1.4° しかないので、接着中は机面+スコヤで shell の水平を出す (2026-09-04 M-04)に決まる。レンズ面は瞳の奥 (標準距離
   6.57mm) に自動的に位置する
4. **組み上がったポッドを Head_Top の中央目ソケットへ、正しい取付位相で
   グルーする**: 左右目 (§2.7) と同じ φ30 貫通ボアへネック (φ28, 回転
   しない固定パーツのため左右目よりネック径を太くして接着代を稼いでいる)
   を通し、シェル内側から接着する。**瞳が水平前方をまっすぐ向く姿勢**
   (組み上がった頭部の前後軸に対し瞳が正面・水平になる向き。現物合わせ
   — 簡易な水準器や頭部の前後基準線を使って目視で合わせる。設計上の
   残差は ~8.6° なので多少のズレは許容範囲) でネックを挿して固定する
   (旧設計の camera_carrier 接着ウィングは分割版で廃止済み)
5. **本体基板の設置と配線**: 本体基板 (ESP32S3 チップ/WiFi アンテナ/
   USB-C) は camera_carrier に載せず、FPC で子基板と接続したまま**頭部
   内部の空きスペース**へ現物合わせで固定する (両面テープ等。頭部内で
   完結)。電源 2 芯のみシャーシ 7 タブ間隙間 (頭部は完全固定で可動部が
   ないため、首の回転部を避ける配慮は不要) から胴へ下ろす — 給電元
   (5V/3A DC-DC) と電流収支の注意を含め `docs/wiring.md`
   「カメラ電源配線」参照
6. **検証**: 形状側は `tools/check_camera.py` が緑 ([1] 外殻無傷+光軸自己
   整合 / [2] FOV ケラレ / [3] 収容干渉 / [4] 全アセンブリ視界 / [5] ネック
   /座グリ整合) であることを確認。実機側はカメラを WiFi (iPhone インター
   ネット共有) へ接続し、HTTP で静止画/MJPEG が取得できることを確認する
   (手順は `docs/voice.md` §5 参照。本体の I2C/PCA9685 バスとは無接続の
   ため、既存電装への影響はない)

## 3. 意匠シェル

- shin_shell: tibia へ下からスライド → M3×40×2 本を横から貫通、ナイロン
  ナット留め
- **shin_shell のループ意匠 (2026-07-31 修正、同日中に方針を再修正)**:
  Leg_Shin_Blue_x4 に造形されているリング/ハンドル状の突起 (元キットでは
  機体内側を向く意匠) が `shell_mod.py OFFSETS["shin_rotz"]=90°` の旧設定
  では機体外側を向いてしまっていた (URDF ビューアのスクリーンショットで
  ユーザーが指摘。「内側に向けた上で、動作の邪魔になるなら削ってよい」と
  許可あり)。
  **第一次対応 (同日、後に不十分と判明)**: shin_rotz を 90→270° (+180°)
  へ変更すればループが内側へ反転すると考えたが、これは誤りだった。
  実スタンディング姿勢・実カメラ視点で 0°/90°/180°/270° を総当たり
  再検証したところ、90° でも 270° でもループは "内向き" ではなく機体中心
  から見て半径方向おおよそ 50-65° (依然として外側寄り、"横向き") にしか
  ならず、外側カメラからほぼ同程度に視認できてしまう (90→270 は実質的な
  改善になっていなかった)。真に内側 (半径方向 176° 程度、ほぼ機体中心を
  指す) を向く角度は shin_rotz≈0° 近辺のみだったが、この角度では脚の
  断面の「厚い側」が隣接脚 (45°ペア, 例 FR-RR) の方向へ向くことになり、
  両脚を firmware の許す最大内寄せヨー+深屈み (pitch45°/knee30°) へ
  同時に取らせると shin_shell 同士が 7-9cm³ も交差する新規の重大干渉が
  発生した。この干渉はシェルの下半分〜中盤 (Z方向85mm超) にわたる面での
  接触であり、局所リリーフでは対応できない規模 (シェル片側の壁をほぼ全長
  にわたり削り取ることになり、ユーザー許可の「飛び出している部分」の
  trim の範囲を明らかに超える) と判断し、Z 回転による "隠す" 対応は
  断念した。
  **最終対応**: ループ/ハンドルの意匠そのものを、raw メッシュ座標に固定
  した位置で直接切除する (`shell_mod.py` `LOOP_RELIEF_*`, shin_rotz の
  回転より前段で適用するため角度に依存しない)。どの角度から見てもループ
  は存在しないため、外側から見えないというユーザー要求を回転よりも確実に
  満たす。これにより shin_rotz は再び自由なパラメータに戻ったため、270°
  を維持: 45°ペア隣接脚干渉が (KNEE_RELIEF/TIP_RELIEF 込みで) ほぼゼロに
  収まる角度帯 (実測で概ね 240°-315°) の中にあり、90° 近辺 (旧来値) は
  同じ隣接脚干渉が 25-30cm³ という致命的な規模になる、今回判明した
  未発見の既存不具合だった (今まで check_leg_assembly.py が shin_shell を
  一度も隣接脚検査に含めていなかったため発覚しなかった。90°/270° は
  カット形状が原点対称という意味では等価でも、干渉相手 (隣接脚) との
  位置関係は回転で大きく変わるため、隣接脚干渉量には全く等価ではない)。
  向き変更・意匠切除後、可動域全域の実メッシュブーリアン再検証で以下が
  判明し、`shell_mod.py` に局所リリーフカットを追加して解消済み:
  (1) **KNEE_RELIEF**: 深い股ピッチ+膝屈曲 (pitch≥35°, knee≥35° 目安) で
  shin_shell (ループとは無関係の別部位) が femur_link (+膝サーボ) と交差
  (無対策で 0.22-0.26cm³。ループの有無・shin_rotz の値によらず存在する
  既存不具合と判明) → T_knee ローカルの該当領域を丸めボックスで除去
  (→0.00cm³, femur/coxa 双方・pitch/knee全域・sim_gait 実歩容192姿勢で
  再検証済み)。
  (2) **TIP_RELIEF**: 隣接脚遠ペア (FR-FL/RL-RR) が両者フルヨー±40°+
  深屈み (pitch45°/knee30°) のときだけシェル下端外縁同士がごく僅かに接触
  (0.0103cm³) → 同様に小さなリリーフカットで解消 (→0.00cm³)。
  **→ 2026-07-31 別タスク「shin_shell のリリーフカット再評価」で両カットとも
  撤去済み** (本節末尾参照) — shin_rotz=0 の現行形状では KNEE_RELIEF の
  干渉自体が再現せず (旧 shin_rotz=270 時に固有の干渉だった)、TIP_RELIEF の
  0.0103cm³ も現行形状では再現しない (残留は 0.000031cm³ = メッシュ数値誤差
  レベルで、しかもその極値点は到達不能姿勢)。
  検証は本タスクで恒久スクリプトとして新設した `tools/check_shin_arm_leg.py`
  (自脚/隣接脚45°ペア (crouch=(45,30)含む)/隣接脚遠ペアの3系統、全て
  0.0000cm³ で PASS) と、既存の `tools/check_leg_assembly.py` (骨格/シャーシ/
  ポッド/バッテリークレードル、shin_shell 込みで再検証、全て 0.0000cm³)
  を使用。
  **既知の未解決項目 (本タスクの範囲外, 新規発見)**:
  (a) shin_shell (現行270°) は READY 姿勢の腕と広い範囲で重なる
  (関節限界姿勢で 10.7cm³, 実歩容由来の姿勢でも 5.3cm³ — shin_shell の
  シェル長の2/3超にまたがる大規模な干渉で、局所リリーフでは対応不可能。
  90°近辺ではこれが 3.1cm³/0.09cm³ まで下がるが、その代わり上記の隣接脚
  干渉が致命的になるため、90°/270° いずれの角度でも「隣接脚」と「腕」の
  両方を同時に満たす shin_rotz は存在しないと判明した。腕マウント位置か
  可動域を変えない限り、firmware 側で脚 yaw/pitch 深追い時に該当側の腕を
  READY へ進めさせない連成クランプ等、別レイヤでの対応を推奨)。
  **→ 2026-07-31 追加タスクで解消**: firmware 側の脚×腕連成クランプ
  (`arms.h`/`config.h` `ARM_LEG_YAW_GATE_DEG`) を実装し、この (a) は解消
  済み。詳細は本節末尾「脚×腕連成クランプ」および §4「歩行調整」参照。
  (b) 45°ペア (例 FR-RR) を片側最大内寄せヨー+crouch=(pitch45°,knee30°)
  にすると tibia_link 同士がごく僅かに接触 (0.0683cm³) — shin_shell とは
  無関係な骨格側の事象として発見された。
  **→ 2026-07-31 タスク#30 で再分類・解消**: この接触を生む
  (pitch,knee)=(45,30) は firmware `gait.h` のワークスペース射影
  (`D_KNEE_MIN`/`D_KNEE_MAX`) の不動点条件を満たさず、歩容コマンド
  (`Gait::update()` 経由) としては構造的に出力され得ないと判明した
  (`tools/sim_gait.py` の実歩容全域スイープ — 体高105-130mm・vx/vy/wz
  全域・全位相で pitch は最大1.3°にしか達せず、pitch>35°かつknee>20°の
  姿勢は0件)。`main.cpp` を確認したところ、脚の関節角は常に
  `gait.update()` の出力経由でのみ書き込まれ、`CALIBRATION_MODE` は
  `allNeutral()` (0,0,0)、`/trim` (web_ui.h) も ±200us≒±18°程度の中立
  オフセットに留まり、歩容制御を経由しない raw 関節コマンドの経路は
  現行 firmware に存在しない。よって tibia_link の形状は変更せず
  (README 鉄則3)、`tools/check_shin_arm_leg.py` [B] のtibia-tibia判定を
  「firmware到達可能集合」(`pk_reachable()`, 同ファイル参照) に限定する
  よう再定義し、worst=0.0000cm³ (PASS, overall に算入) へ解消した。
  **限定条件**: この解消は gait.h のワークスペース射影という物理クランプ
  に依存する。歩容制御を経由しない raw 関節コマンドの経路が将来
  firmware に追加された場合は 0.0683cm³ の接触が理論上再現し得るため、
  そのような経路を追加する際は `pk_reachable()` のゲーティング前提ごと
  見直すこと。
  (a) は overall PASS 判定に既に算入済み (脚×腕連成クランプ)。
  (b) も本タスクで overall PASS 判定に算入されるようになった。
  shin-shin 側の別項目 (worst=0.84cm³) は本タスク (#30) の対象外で当初は
  従来どおり KNOWN NG (閾値1.0cm³未満) として PASS 扱いのままだったが、
  **→ 2026-07-31 別タスク「shin_shell のリリーフカット再評価」で解消済み**:
  `BOLT_BOSS_KEEPOUT_X` (この 0.84cm³ の主因だった M3ボルト座面確保用の
  ハード制約カット) を含む `ADJ_RELIEF_BANDS` 全体を、到達可能集合内で
  干渉ゼロと確認の上で撤去しキット形状へ復元した。詳細は本節末尾
  「2026-07-31 リリーフカット再評価」参照。
  Leg_Thigh_Guard_Blue_x4 (フック/シールド状の別パーツ, femur 上部の
  thigh_cap に搭載) は現状変更なし — Z 軸回転を振っても外観がほぼ変化
  しない (ドーム状で顕著な指向性が無い) ことを 4方向レンダで確認済みで、
  既存の 3MF フォレンジクス由来の近似恒等回転 (kit_assembly_front.json
  matrix_note) を維持するのが妥当と判断
- **shin_shell 装飾面の放射外向き確定 (2026-07-31, 実物写真タスク — 上記
  ループ切除タスクの直後に発生。shin_rotz を 270°→0° へ再変更)**:
  ユーザーが同キットの実物 (塗装済み完成品) の写真2枚 (前面ビュー+手持ち
  斜めビュー) を提示し、次の決定的事実が判明した: (1) 脚の脛シェルは
  上部外側面に 3 つの小さなドットモールドがはっきり見え (前脚2本とも
  同位相=外向き)、太もも部にも同様の3ドットが外向きに見える。パネル
  ライン (筋彫り) も外側面に走る。(2) ループ/フック類はどの角度からも
  一切見えない (内側に隠れている)。ユーザー指示原文: 「基本的に足の
  側面のパーツは全て外側を向いています。放射線の軸から見て外側に側面の
  パーツが来るようにして欲しいのです」。
  1. **装飾フィーチャの特定**: raw `Leg_Shin_Blue_x4.stl` 上で
     sharp-edge 連結成分解析 (face_adjacency_angles>15°) を実施し、上記
     ループ (raw 中心 (-9.47,-0.02,34.1), 平均面法線 raw≈(-0.782,0.002,
     -0.623)) の**正反対の面** (X>0 側) に 3 点の小さな円形クラスタ
     (中心 raw (11.87,0,40.19) と左右対称ペア raw (14.17,±2.14,36.48)、
     3点合成中心 raw (13.40,0,37.72)、平均面法線 raw (0.852,-0.001,
     0.523) = 局所 +X 支配的) を発見。これが「3 ドットモールド」。
     同じ +X 側に、シェルほぼ全長 (raw Z∈[-46.45,33.55]) にわたる長尺の
     sharp-edge 連結成分 (raw X∈[12.26,17.13], Y∈[-10.61,10.61], 698頂点)
     も存在し、これが「主パネルライン」と同定。thigh_cap (Leg_Thigh_Grey
     由来) は独立回転パラメータを持たないため raw メッシュ自身のモデリング
     軸が femur ローカル系にそのまま使われる — Thigh_Guard は上記の通り
     指向性なしと既に確認済みで本タスクでは変更なし。thigh_cap 自体の
     ドット特定は sharp-edge 解析でも 1mm 未満の微小候補しか見つからず
     (筐体が小さく意匠が浅いため) 数値的な単離はできなかったが、
     thigh_cap に独立回転パラメータが存在しない (raw メッシュの軸が
     そのまま femur ローカル系の軸になる) 以上、"直す" 対象にはならない
     — レンダ (`docs/vis_shin_orientation_check.png`) で外観が破綻して
     いないことを確認した
  2. **向きの決定**: shell_mod.py `shin_shell()` の構築パイプライン
     (raw→scale→XY中心化→LOOP_RELIEF切除→**shin_rotz回転**→各種チャネル/
     リリーフカット) を模した python で、上記ドット3点の合成法線を
     tibia ローカル系へ写像し、4脚それぞれの実スタンディング IK 姿勢
     (STANCE 方位直接到達式, sway非依存) での T_knee 全回転
     (Rz(mnt+yaw_d)·Ry(pitch_d)·Ry(knee_d), ミラー脚は診断的に Y反転を
     追加適用) を合成、法線の world 水平投影とその脚の放射方位
     (mnt+yaw_d) との cos 類似度を shin_rotz∈[0°,355°] で 5°刻み走査した。
     結果: **shin_rotz=0.0° で 4 脚 (FR/FL/RL/RR) 全て cos_sim=1.000**
     (完全に放射外向き) と数値確定。180° は cos_sim=-1.000 (真逆の最悪角)、
     旧採用値 270° 近辺は cos_sim≈-0.16 (ほぼ横向き、写真の見た目と不一致)。
     4脚ともミラー込みで同一角度に収束するのは、ドット法線の局所Y成分が
     ほぼ0 (raw -0.001) で、T_knee の回転チェーンが局所+Xを各脚固有の
     放射方位へそのまま写す構造になっているため (幾何学的に自明、脚ごとの
     個別チューニング不要)。主パネルラインも同じ +X 面にあるため同じ
     shin_rotz=0° で追従して外向きになる。ループ (LOOP_RELIEF で既に
     切除済み) は正反対の面なのでドット外向き=ループ内向きが同じ角度で
     同時に成立し、写真の「ループ不可視」とも整合する
  3. **干渉リリーフ**: shin_rotz を 270→0 へ戻すと、旧経緯 (上記) で
     判明していた「45°ペア隣接脚 crouch 干渉が 7-9cm³ 級で再燃する」
     角度帯に入る (実測 worst 8.4860cm³, FR-RR crouch(45,30) 系)。
     pairs45 の4通り×IK到達極値姿勢の全組合せで実ブーリアン交差を
     全数探索し、交差領域点群を RR (非ミラー基準) の tibia ローカル系
     Z 4バンドへ分けて各バンドの実測 X/Y 範囲+3mmマージンで箱化
     (`shell_mod.py` `ADJ_RELIEF_BANDS`) — 段々畑状に積むことで単一の
     巨大ボックスより不要な削り込みを抑えた。この段階で shin-shin 干渉は
     ほぼ0まで低減したが、ADJ_RELIEF が BOLT_ZS (M3×40 ボルト2本の通し穴,
     make_leg.py tibia_link() と一致) の座面壁も丸ごと削ってしまう
     副作用が判明 (断面実測: Z=-100 で座面 Y範囲 9.5-19.15mm がゼロに
     消失)。単純に箱を足し戻す方式は周囲を全周カットで囲まれた浮遊
     アイランドになり `decompose()` の「最大連結成分のみ残す」処理で
     消えることを実測で確認したため、**カットそのものから X∈[-4,4]の
     縦通し柱を除外**する方式に変更 (`BOLT_BOSS_KEEPOUT_X=4.0`, M3 φ4
     クリアランス穴の周囲に約2mm の実壁厚を確保する印刷可能な下限)。
     ボルトを含まない band1/band3 まで柱を残すと干渉が余分に増えると
     判明したため、has_bolt=True の band2/band4 のみに限定。最終結果:
     45°ペア crouch worst = **0.8404cm³** (無対策 8.49cm³ から 90%削減、
     全4バンド柱ありの中間実装 1.4756cm³ からさらに 43%削減)。この残留
     分は M3 ボルト座面というハード制約 (締結強度) と可動域干渉という
     ソフト制約が直接衝突する箇所で、ゼロ交差より締結強度を優先した
     判断 (ユーザー許可「動作の邪魔になる部分は削ってよい」は削る許可
     であって締結部を犠牲にする指示ではないと判断)。`tools/
     check_shin_arm_leg.py` [B] が KNOWN NG として明記し続ける (ceiling
     1.0cm³ で regression 検出は維持)。カットの可視性: ADJ_RELIEF は
     tibia ローカル Y>0 側 (=RR 基準で計測した隣接脚 (FR) に向く側、
     ドット面である local X≈20,Y≈0 からは Z 方向に最低 17.4mm 離れて
     おり非接触) のみに限定し、外側ドット面には一切触れていない。
     パネルライン意匠との重なりは実測で確認済み (raw sharp-edge 帯
     3054面中 480面=15.7%が ADJ_RELIEF footprint 内、残り84.3%は温存) —
     45°ペア crouch という関節限界姿勢限定の副作用であり、通常立位・
     通常歩容では露出しない
  4. **検証**: `tools/check_shin_arm_leg.py` (自脚0.0000cm³/隣接遠ペア
     0.0000cm³/近ペア0.8404cm³=KNOWN NG/腕干渉7.91cm³=既存KNOWN NG,
     overall=PASS), `tools/check_leg_assembly.py` (shin_shell非依存の
     骨格/シャーシ/ポッド/クレードル全項目0.000cm³, OK), `tools/
     check_urdf.py` (380項目 OK=380 NG=0) で再検証済み (当時)。`Leg_Shin_Guard_
     Grey_x4` の取付行列は shin_rotz の +90° 分だけ単純co-rotationした
     ところ ADJ_RELIEF が座面の壁を削った領域と重なり embed 34.2%まで
     劣化したため、6-DOF differential_evolution で再フィット
     (80.1%embed/median1.714mm/maxfloat3.525mm, `kit_assembly_front.json`
     matrix_note_2026_07_31c 参照)。レンダ (新規プロセスで生成、
     `docs/vis_shin_orientation_check.png` 標準立位の正面/側面/上面+単脚
     クローズアップ、`docs/vis_shin_shell_detail.png` shin_shell単体の
     ドット面/パネルライン確認) で最終確認。**→ 2026-07-31 別タスク
     「shin_shell のリリーフカット再評価」で ADJ_RELIEF_BANDS 自体を撤去した
     ため、上記 0.8404cm³/80.1%embed はいずれも過去の値 — 現在は
     shin-shin worst=0.0000cm³ (到達可能集合基準)、ガード embed は
     行列無変更のまま 87.4% へ自動改善 (本節末尾「2026-07-31 リリーフカット
     再評価」参照)。
- **2026-07-31 リリーフカット再評価 (「削る理由が消えたカット」の撤去)**:
  タスク#30 で tibia-tibia の crouch(45,30) 干渉が firmware `gait.h` の
  ワークスペース射影 (`D_KNEE_MIN`/`D_KNEE_MAX`, `pk_reachable()`) 下では
  歩容コマンドとして到達不能と厳密証明されたことを受け、shin_shell の
  各リリーフカットも同じ「firmware 到達可能集合内で干渉するか」基準で
  再評価した。方針の優先順位は (1) キット形状のまま残す > (2) 動作に本当に
  邪魔なら削る、で、判定基準はタスク#30 と統一 (shin-shin/femur-shin にも
  `pk_reachable()` を適用)。

  | カット | 旧根拠 (発見時の干渉) | 到達可能集合での再測定 | 判定 |
  |---|---|---|---|
  | `LOOP_RELIEF` | ループ意匠が外側から見える (旧shin_rotz時) | (復元可否を別途検証, 下記) | **維持** (印刷可能な形で復元不可) |
  | `KNEE_RELIEF` | femur_link と干渉 0.22-0.26cm³ (旧shin_rotz=270時) | pitch∈[-45,55]°×knee∈[-44,44]° 全域 (到達可否問わず) worst=0.0000cm³ | **撤去** |
  | `TIP_RELIEF` | 遠ペア crouch(45,30) で下端接触 0.0103cm³ | 同条件 worst=0.0000cm³ (拡張走査でも 0.000031cm³=数値誤差レベル、その極値点も到達不能) | **撤去** |
  | `ADJ_RELIEF_BANDS`+`BOLT_BOSS_KEEPOUT_X` | 45°ペア crouch(45,30) で最大8.49cm³ (無対策)、既知残留0.84cm³ | 到達可能集合限定の45°ペア全組合せ worst=0.0000cm³ (カットの有無に関わらず) | **撤去** |

  **各カットの再測定方法**: `shell_mod.py` の `shin_shell()` を複製し
  各カットを個別に無効化した変種を生成、対応する干渉テスト (自脚
  femur/coxa、隣接45°ペア shin-shin、隣接遠ペア shin-shin) を
  `pk_reachable()` で到達可能集合に絞って再実行。KNEE_RELIEF は現行
  shin_rotz=0 の形状では pitch/knee 全域 (到達可否を問わず) で干渉自体が
  再現しなかった (旧干渉は shin_rotz=270 時の形状固有だった)。

  **LOOP_RELIEF (ループ) 復元の検討**: ユーザー指示「ループは内側に向けた
  上で、動作の邪魔になるようであれば削って構わない」を踏まえ、現行
  shin_rotz=0 (ループが内側=非可視) でループを削らず残せないか検証した。
  結果、LOOP_RELIEF を外すと `shin_shell()` は常に2パーツに分解される
  (メイン本体 + ループ片1.12cm³) — 原因は隣接脚等との干渉ではなく、
  `UPPER_CAVITY` (クレビス+集約ブロックを飲み込む機能上必須の空洞) が
  ループの付け根をちょうど切断してしまうこと。分離したループ片は
  `shin_shell()` 末尾の「最大連結成分のみ残す」処理でどのみち捨てられる
  ため、印刷物には現れない (無意味な変更)。UPPER_CAVITY 自体は機能上
  削れないため、ループを物理的に接続したまま復元するには UPPER_CAVITY の
  形状再設計 (ブリッジ追加等) が必要で、単純なカットの撤去では対応できない
  と判明した。よって **LOOP_RELIEF は維持** (「動作の邪魔」ではなく
  「そもそも印刷可能な形で復元できない」ため)。

  **撤去後の再生成・検証**: `hardware/src/build_all.py` で shin_shell.stl/
  shin_shell_m.stl を再生成 (watertight, 単一連結成分, 59.1cm³→82.0cm³)。
  `tools/check_shin_arm_leg.py` を全面 PASS で再確認 ([A]自脚0.0000cm³
  [B]shin-shin(到達可能集合)0.0000cm³ [参考:物理全域8.486cm³]
  /tibia-tibia(到達可能集合)0.0000cm³ /遠ペア0.0000cm³ [C]腕クランプ
  0.0440cm³<ceiling0.08cm³、overall=PASS)。旧 `KNOWN_BOLT_BOSS_CEILING`
  特例ロジックは不要化のため削除し、shin-shin 判定も tibia-tibia と同じ
  到達可能集合基準に統一した。`tools/check_urdf.py` (380項目 OK=380
  NG=0)、`tools/check_leg_assembly.py`、`tools/check_screw_bosses.py`
  も全て green で再検証済み。

  **Leg_Shin_Guard 取付行列**: `ADJ_RELIEF_BANDS` 撤去でガードが接する壁
  (Z -107..-74) がキット形状へ復元されたため、既存の80.1%フィット行列
  (`kit_assembly_front.json` matrix_note_2026_07_31c) を**無変更のまま**
  復元後の shin_shell() に対して再検証したところ、embed 80.1%→87.4%
  (887/1107→968/1107頂点)、max float 3.525mm→2.725mm へ自動的に改善した
  (壁復元の副次効果、行列自体は変更していない)。史上最良だった 2026-07-28
  時点の 82.8%embed/median1.585mm/maxfloat6.552mm (ADJ_RELIEF導入前) と
  比べても embed%・max float とも上回る。同じ6-DOF re-fit手法を復元後の
  shin_shell() に対して念のため再実行したが 83.1%embed/maxfloat6.33mm と
  無変更の方が全指標で優れていたため (re-fit のコスト関数は「1mm均一
  embed」を狙うもので embed%最大化とは目的が異なる)、行列は更新せず維持
  した (`kit_assembly_front.json` matrix_note_2026_07_31d 参照)。

  **重量**: shin_shell が material 復元により +17g/セット (×4で
  ~147g→~164g、`docs/filament.md`/`docs/print_manifest.md` 参照)。

  **URDF/Isaac Sim への影響 (`docs/urdf.md` 参照)**: `pk_reachable()` に
  基づく「到達不能」判定は firmware の歩容射影 (`gait.h` の
  `D_KNEE_MIN`/`D_KNEE_MAX`) というソフトウェア側のクランプに依存して
  おり、URDF を Isaac Sim 等へ取り込んで関節を直接駆動する場合はこの
  クランプを経由しないため、crouch(45,30) 級の極端姿勢では shin_shell
  同士が実際に接触し得る (シミュレータ上のみで発生し、実機では歩容射影が
  防ぐ)。

  詳細な数値・判定根拠は `hardware/src/shell_mod.py` の該当コメント、
  `tools/check_shin_arm_leg.py` [B] 節のコメントを参照。
- thigh_cap: femur 上面ブリッジへ接着 (ホットボンド推奨=脱着可)
- Leg_Toe ×3/脚 (元キット STL 150%, 無加工): leg_foot_bored の甲底面に元々
  ある 3 本の一体成形スタブ (根元 φ5mm→先端 φ2.4mm のテーパー円錐, 実測で
  XY 角度は概ね -90°/+40°/+140° の非等間隔トライポッド — 完全な等間隔
  120° ではなくキット原型どおりの配置。**3本とも実際にトゥの取付先**、
  2026-07-29 に旧-90°スタブの誤短縮を復元しキット原型を完全復元済み) へ、
  トゥの太い付け根面をスタブの向きに合わせて瞬間接着する。トゥの軸まわり
  ロール (爪の湾曲=腹側) は接地方向 (world -Z) を向くよう幾何学的に確定
  済み (完成写真で爪先が地面側へ垂れ下がる様子と整合)。接地力は主に隠し
  TPU パッド (foot_pad) が受ける設計で、トゥは装飾として甲から外側・
  下向きに長く突き出す (foot-甲 embed 4.8-4.9%・トゥ同士の相互干渉ゼロを
  実メッシュで確認済み — tools/data/kit_assembly_front.json の
  Leg_Toe_Black_x12 エントリ参照)。トゥの根元には深いソケット穴は無く
  (平面的な接着継手)、瞬間接着剤でスタブへしっかり固定すること
- Leg_Shin_Guard ×1/脚: shin_shell 中程 (膝から下 ~70-90mm, M3 ボルト穴の
  中間帯) の外側面へ瞬間接着。2026-07-28 監査で旧「~2mm 均一埋め込み」の
  自己申告値が実メッシュと乖離していたと判明し、実測ベースの6自由度フィット
  に置き換え (73.0%embed) → さらに 2026-07-28 のレビューで、この版を
  ハイライト再レンダしたところ依然として扇形に浮いて見えると判明したため、
  最大突出量にもペナルティを課した3回目のフィットへ更新済み
  (tools/data/kit_assembly_front.json Leg_Shin_Guard_Grey_x4 の "matrix" 参照,
  82.8%embed / 中央値1.58mm。**2026-07-28 レビューで発覚**: この数値は
  非ミラー脚 (FL/RR) の shin_shell に対してのみフィットされており、
  ミラー脚 (FR/RL, shin_shell_m 使用) では同じ行列をそのまま流用すると
  26.7%embed まで悪化する不具合があった → tools/make_visuals.py 側で
  ミラー脚の場合だけガードにも同じ Y ミラーを掛けるよう修正し、FR/RL も
  FL/RR と全く同じ 82.8%embed/中央値1.58mm を達成するようになったため、
  現在は4脚とも上記数値がそのまま当てはまる)。**この再フィットでも見た目の改善はごく僅か
  だった** — 目的関数を変えても最大突出量 (6.90mm→6.55mm) がほとんど
  縮まらなかったことから、ガード自体の曲率が shin_shell の局所曲率と
  根本的に一致しないと確認できた (局所的に最大 ~6-7mm 浮く/めり込む部分は
  解消しない)。**現物合わせでのパテ/ヤスリによる追い込みがほぼ必須**と
  考えること — キットの本来の勘合先が特定できなかったため意匠アクセント
  としての reasoned 配置であることに変わりはない
- ガード類 (その他): シェルと膝サーボの突出ケースを覆うように接着
- **膝カバーの検討 (2026-07-31, 判定=見送り)**: ユーザーから「膝が露出して
  接合されていないように見える」との指摘があり、`Leg_KneeJoint_Grey_x4`
  (`print_manifest.md` #46「不使用」) で膝の露出部を覆えないか実測した。
  結果: 150%換算で `Leg_KneeJoint_Grey_x4` の外形は 18.9×30.2×30.2mm
  (最大辺30.2mm) に対し、`thigh_cap` の遠位端 (femur ローカル X=46.2mm) から
  膝軸 (X=70mm) までの露出 femur が23.8mm、`shin_shell` の近位端
  (tibia ローカル Z=-24.5mm) から膝軸 (Z=0) までの露出 tibia が24.5mm ―
  **露出部は合計約48mmと`Leg_KneeJoint_Grey_x4`の最大辺(30.2mm)より
  大きく、しかも膝±44°の回転クリアランスをまったく考慮していない単純な
  外形比較でも既に覆いきれない**。よってこのキット付属パーツの流用 (無加工
  または縦割り/中抜き加工) では膝の露出解消は成立しないと判断し、実装は
  見送った。代替案として shin_shell の近位端 (現状 Z=-24.5) と thigh_cap の
  遠位端 (現状 X=46.2) をそれぞれ膝軸側へ延長し露出帯を縮める案が考えられる
  が、これは元キットに存在しない新規シェル形状の設計を伴うため
  (「見える形状は元キット準拠」の方針外)、本タスクでは実装せずユーザー
  確認事項として残す。
  **2026-07-31 ユーザー決定 (確定, 頭部中央寄せタスクと同時提示)**:
  「②メカ剥き出しの見た目で」。上記の実測結果 (`Leg_KneeJoint_Grey_x4`
  流用不可、露出48mm vs パーツ最大辺30.2mm) を踏まえ、**膝はメカ剥き出し
  のまま確定** — `Leg_KneeJoint_Grey_x4` は不使用のまま、新規カバー形状も
  作らない。今後のセッションでこの論点を再検討する必要はない。
- Head (前面の顔球体): **Head_Top** はシャーシ周囲の 7 タブと現物合わせ →
  シェル内面にホットボンド。**Head_Top は必ず `Head_Top_Eyecut.stl`
  (2026-08-22 v2: 目ボア + 内部機構逃がし) を印刷する** — 元 Head_Top は
  ほぼ中実彫刻 (306cm³) で、プレート上 z≈10-14 の「床」が脚ヨーサーボ
  ケース ×4 (各 5.5cm³)・腕サーボケース ×2・タブビス頭・PCA board0 と
  交差し、**そもそも被せられない** (実メッシュブーリアン確定 2026-08-22,
  落とし穴 #55 の Head_Top 版)。v2 は外皮 ~3mm を残して内部をホロー化
  (306→52cm³) + 下部スカートに脚/腕ケース用ノッチ 6 箇所を焼き込み済み
  (`tools/make_head_eyecut.py` の検算 [1]-[7] が恒常担保: ケース/ビス頭/
  PCA スタック包絡と交差 0、スタック→内面 実距離 3.1mm、外皮残存 98.7%、
  目ソケット座材 1.4cm³/箇所)。目ソケット座グリと φ30 ボア周囲は壁が
  残るので eye_carrier の接着座はこれまで通り。
  **Head_Bottom_Armcut (2026-08-20 機構逃がし
  カット後)** は浅いボウル形で、上端の平坦リング面 (プレート下面-0.5mm) を
  **プレート下面へホットボンド**する (旧記述「7 タブと現物合わせ」は
  Head_Bottom には適用不能 — タブ r78-86 はボウル r54.7 の外側で届かない。
  腕ソケットに通る shoulder_bracket ×2 が位置決めを兼ねる)。ボウル底の
  大開口はバッテリー窓+挿入経路 (2S パックは従来どおり -Y 側から
  battery_cradle へ抜き差しできる)。前脚 coxa 用ノッチ×2・後脚用×2 も
  焼き込み済み (脚ヨー±40°+3° で干渉 0, `make_head.py __main__` 検算)。
  キットで上下シェル間に挟まれていた Head_Plate (グレー円板) は**印刷・
  使用しない** — その層はシャーシプレート自体が置き換える (プレート
  φ144+タブは頭球 φ124.4 より広いため、合わせ目でプレート縁が露出する。
  完全な外観維持が欲しくなったら「プレート上面の化粧リング」別パーツ化を
  検討 — `hardware/src/make_head.py` docstring 参照)。**Head_Bottom_Cap_Grey
  (キット積層順最下段の底蓋) も使用しない** — 旧キャップ座 (底中央 r7.5..20)
  はバッテリー窓に消滅しており、装着するとバッテリー交換を塞ぐ。
  (キットの積層順: Top → Plate → Bottom → Bottom_Cap のうち Plate/Bottom_Cap
  が不使用になる)。**頭部に可動部は無い**
  (首は回らない。CH_HEAD [ch12] は2026-09-05から予約専用・常時PWM停止。詳細 `docs/wiring.md`「頭部ヨー
  (CH_HEAD) の物理対象」)。`Head_Dome_Grey`/`Head_Peg_Upper`/`Head_Peg_Lower`
  は他の Head 一式パーツ同様、無加工のまま印刷して接着するだけでよい
  (前者は前頭部の装飾リベット、後者2点は Top⇔Bottom を内部で軸合わせする
  組立ダウエルと推定される — いずれも本タスクでは通常の接着組立の対象)。
  ※2026-08-22 の Head_Top 内殻ホロー化で、ダウエルの Top 側受け座
  (床の内部フィーチャー) は彫り込みで消滅している可能性が高い — 本ビルド
  では Top⇔Bottom 間にシャーシプレートが挟まりダウエルは元々機能しない
  ため、Peg 2 点は**接着装飾または省略**とする (不可視の内部パーツ)
- **頭部中央寄せ (2026-07-31 ユーザー決定①B, 実装完了)**: 前回セッションでは
  `ARM_MOUNT_HUB_Y` (頭部中心軸のシャーシ y オフセット) を 12.0mm→0.0mm
  (完全中央) へ変更すると `pod_neck` 背面ブラケットとの実体干渉が
  1.59cm³→4.59cm³ へ悪化するため見送っていた (旧記述は本ファイル履歴参照)。
  ユーザーから改めて「①B: 頭部の中央寄せを `pod_neck` 側の逃がしカットで
  実現する (強度検証込み)」の指示を受け、以下の設計で実装した。

  **1. 干渉域の精密特定**: `hub_y=0` での実メッシュ交差 (4.59cm³) の
  内訳をグリッドスキャンで調べたところ、干渉域は `pod_neck` の基部
  ブラケットパッド (プレート後端, `y=[POD_NECK_Y0-15, POD_NECK_Y0+15]
  =[-73,-43]`, M3×4 でプレートへ共締め) の footprint にほぼ完全に収まって
  いた (実測 `y=[-62.7,-43]`)。この帯は「チャシプレート直上 = 頭部
  シェルの中空内部」という、そもそも隠しブラケットが常駐して当然の領域
  (PCA9685/ESP32/battery_cradle など他の隠し電装と全く同じ立ち位置) にあり、
  `y=-43` 近傍ではブラケット厚みゼロ (プレート直上, `z_local=0`) でさえ
  頭部シェル境界の内側にある — **「頭部シェル全域から2mmクリアランス」を
  額面通り満たすことは、このブラケット帯に限っては `pod_neck` をどれだけ
  削っても原理的に不可能**と判明した (0mm/2mm/4mm/6mmいずれの厚みでも
  `y=-43〜-45` 近傍では頭部シェル境界の内側に入る)。

  **注記 (不可視性の根拠)**: この逃がしカットが外から見えないのは
  **`Head_Bottom`/`Head_Top` 頭部シェルの中空内部に収まるため**であり、
  `Head_TailJoint_Blue`/`Ball` (化粧キャップ) の被覆によるものではない。
  `pod_neck` は基部 (`POD_NECK_Y0=-58`, 頭部シェル寄り) から `-Y` へ
  `POD_NECK_LEN=46mm` 張り出し、TailJoint が被さるのは反対側の先端
  (`y≈-104`, Cabin 接続側) — 今回カットが効く帯 (`y∈[-73,-43]`) は
  TailJoint の被覆範囲の外にあり、逆側の頭部シェル寄りに位置する。

  **2. 採用したカット設計**: 基部ブラケットパッドを「シャーシ直上の隠し
  実装として頭部シェル内にあって当然の除外域」と位置づけ、`pod_neck` の
  うち **除外域 (`|x|<20, y∈[-73,-43], z_local<HEAD_RELIEF_PROTECT_H`) より
  上にある梁の "余剰高さ"** だけを、頭部クラスタの実メッシュ (`hub_y=0`
  配置) + マージン2mm分カットする方式を採用した
  (`hardware/src/make_chassis.py _head_relief_cutter()`)。除外域自体は
  「内部実装として保護」し、それより外側 (梁本体・先端絞り・フランジ、
  および除外域より高い残存梁材) は交差0+クリアランス≥2mmを要求する。

  **3. 強度検証 (工学計算)**: 除外域の厚み `HEAD_RELIEF_PROTECT_H` を
  カット後の最弱断面での曲げ応力計算で決定した。

  **2026-07-31 QA 再検証で全面改訂** (下記 a〜c の指摘を修正): 初回計算に
  (a) 重心の加重平均に算術誤り (363×167.1+171×229.0)/534 の計算結果を
  誤記, (b) レバーアームに 2 つの異なる基準点 (基部パッド前端 y=-43 / 最弱
  断面 y=-50) の値が σ 計算と安全率の記述で無自覚に混在, (c) 応力集中係数
  (Kt) が未考慮、の 3 件の不備があった。以下は実メッシュから断面二次
  モーメントを直接数値積分し直した再計算 (`Z = I_xx/c`, 単純な「幅×高さの
  矩形近似」ではなく実際のボルト穴減肉・丸め形状を含む断面形状から算出)。
  - 荷重: Cabin ポッド系実重量 = **587.4g** (`tools/filament_calc.py` の
    printed_cm3 モデルで `Cabin_Front_Blue`/`Cabin_Back_Blue_Repaired`/
    `Cabin_Peg_x2`/`Cabin_Turrent_Left/Right_Grey`/`Cabin_RedLight_Large/
    Small_Red_x4`/`Cabin_Spinnarette_Grey_x4`/`Cabin_Front_Insert_*` 全6種/
    `Cabin_Turret_Peg_x2`/`Cabin_Eye_White` を実メッシュ体積から積算)。
    600g に切り上げて計算 (安全側)。動的係数2 (歩行 sway/加速) を掛けた
    等価荷重 `F = 0.6kg × 9.81 × 2 = 11.77N`
  - **重心 (訂正)**: `Cabin_Front_Blue` (world centroid y=-166.96mm,
    printed_cm3 モデルでの質量推定 362.8g) と `Cabin_Back_Blue_Repaired`
    (centroid y=-229.88mm, 171.1g) を、実際の配置変換
    (`tools/make_visuals.py shell_ghosts()` と同一の bbox中心化→×1.5→
    回転→並進) を適用したメッシュから直接再計算。質量加重平均
    `y = (362.8×(-166.96)+171.1×(-229.88))/(362.8+171.1) = -187.1mm`
    (旧記載 `y≈-184mm` は算術誤り — 質量×centroid の合計を正しく割ると
    -187.1 になる。小物装飾パーツは Front 近傍にあり重心への影響は僅少)。
  - **最弱断面 (初回計算, y=-73〜-43mm限定走査)**: `y` を -73〜-43mm で
    0.5mm 刻みに走査し、断面二次モーメント法で断面係数 `Z=I_xx/c` を
    比較した結果、`y=-50` (ボルト穴 `y=POD_NECK_Y0+8` の中心) が
    区間内での最小値 (=Z が最も小さい断面) だった。レバーアームはこの
    断面 (`y=-50`) から重心まで `137.1mm ≈137mm` を使う。
    `HEAD_RELIEF_PROTECT_H=4.0mm` (元のパッド厚みのまま, 検討時の最初の案)
    の場合 `Z=67.2mm³` → `σ=M/Z=(11.77N×137.1mm)/67.2mm³=24.0MPa`、
    PETG曲げ強度70MPa (文献値 UNVERIFIED) に対し**安全率2.91 —
    要求安全率3をわずかに下回り不足**と判定し、`HEAD_RELIEF_PROTECT_H` を
    4.0mm→**8.0mm** へ増厚した (頭部シェル内部にあり外から見えないため
    増厚しても意匠上の制約はない)。加えて、指摘 (c) — カッターの y 方向
    境界 (`_head_relief_cutter()` の `lo[1]` 付近) で梁高さが垂直な段差状に
    落ちており、段付き梁の曲げに典型的な応力集中源になっていた — に対応
    するため `CHAMFER_RUN_MM=12.0mm` の直線テーパー (`_y_chamfer_wedge()`)
    を追加し、段差を頭部クリアランス判定の対象域より外側 (y がより負、
    頭部から遠い側) へ滑らかに遷移させた (内側に置くと
    `tools/check_head_pod_clearance.py` の除外域 footprint 外にはみ出し
    新規干渉になることを実装時に確認済み — 上記コメント参照)。

  **2026-07-31 QA 再検証 (2回目) で手法上の不備を修正**: 上記の計算は
  「`Z(y)` が区間内で最小になる断面 (`y=-50`)」を単独で特定し、そこに
  重心までのレバーアームを掛けて `σ=M/Z` を出す方式だった。しかし
  カンチレバー梁の曲げ応力は位置ごとに `σ(y)=M(y)/Z(y)`
  (`M(y)=F×|y-CoG|`) で決まり、`Z(y)` が最小の点が必ずしも `σ(y)` が
  最大になる真の最弱点とは限らない (`y=-73〜-43` に限定した走査自体も、
  レバーアームが最大になる基部側 `y=-43` 付近を十分に見ていなかった)。
  `tools/check_pod_neck_strength.py` (本指摘を受けて新規作成した独立の
  再現可能な検証スクリプト) で、pod_neck 実寸の全区間
  (`y=-108〜-43`, 実メッシュ bounds 全域) を 0.2mm 刻みでスキャンし直し、
  各断面で `σ(y)=M(y)/Z(y)` を直接評価した結果:
  - **真の最弱点は `y≈-43.5`** (基部ブラケットパッドに近い側。`Z=194.8mm³`
    は `y=-50` の `Z=190.3mm³` よりわずかに大きいが、レバーアーム
    `arm=143.6mm` (`y=-50` の `137.1mm` より約6.5mm長い) が支配的になり、
    合成応力はこちらの方が大きい): `σ=8.68MPa` →
    **`SF_nominal=8.06`** (`y=-50` 固定点方式の `8.25` よりやや低い)。
  - `Kt` を掛けた実効安全率: `SF_effective = 8.06/Kt` =
    **`Kt=2.5` で `3.23`** 〜 `Kt=1.5` で `5.38`
    (`y=-50` 固定点方式の `3.30`〜`5.50` よりやや低い)。
    **要求安全率3は全 `Kt` 範囲で依然として上回る (2026-09-05のホスト/材料仮定上の
    PASS。実機の印刷強度・荷重合格へ読み替えない)**。
  - **マージンの訂正**: 最も保守的な `Kt=2.5` でのマージンは
    `3.23/3.0-1=7.6%` — 旧記載の「約10%」は `y=-50` 固定点の過小評価に
    基づく楽観値だった。真の最弱点基準では**実マージンは約7〜8%**
    (旧記載よりおよそ2.4ポイント低い) というのが正しい認識。
  - `y=-50` は依然としてボルト穴による減肉が支配的な局所最小点であり、
    今回の全区間スキャンでも `Z(y)` 単体の最小点自体は梁先端の丸ポスト
    絞り付近 (`y≈-104`, レバーアームが短いため合成応力への寄与は小さい)
    に移る — 「`Z(y)` 最小の一点」と「`σ(y)=M(y)/Z(y)` 最大の一点」は
    一致しないことが、この設計でも実証された。
  - **応力集中係数 (Kt) の扱い**: 実メッシュの断面二次モーメントは平均
    応力 (公称応力) の evaluation であり、上記フィレット/テーパーを
    加えてもなお局所的な Kt は未定量化 (FEA 未実施, UNVERIFIED)。段付き
    平板の曲げに関する文献のチャート (Peterson 型, D/d≈1.5-2 相当・本設計
    のテーパー比に相当する r/d 目安) から、**Kt ≈ 1.5-2.5** 程度と保守的
    に見積り、これを丸ごと安全率へ掛け合わせて評価している。真の最弱点
    (`y≈-43.5`) はテーパー区間からも離れているため、テーパー由来の Kt は
    上記見積りよりむしろ小さいはずだが、保守側に倒して同じ Kt レンジで
    評価した。
  - **今後の再計算方法**: `HEAD_RELIEF_PROTECT_H`/`CHAMFER_RUN_MM`/
    `ARM_MOUNT_HUB_Y` 等を変更する際は、`Z(y)` が最小の一点だけでなく
    `.venv/bin/python tools/check_pod_neck_strength.py` で梁全区間の
    `σ(y)=M(y)/Z(y)` を再スキャンし、真の最弱点で安全率と `Kt` 込みの
    実効安全率を再確認すること (`y=-50` などの固定点だけを見る旧手法は
    使わない)。
  - 検算に使った実測値・グリッド走査結果は本タスク実施時の再現手順として
    `hardware/src/make_chassis.py` の `_head_relief_cutter()`/
    `HEAD_RELIEF_PROTECT_H`/`CHAMFER_RUN_MM` コメント、および
    `tools/check_pod_neck_strength.py` (2026-07-31 QA 再検証で新規作成、
    全区間 `σ(y)` スキャンの正本) を参照。断面係数の数値積分は trimesh の
    平面切断 (`mesh.section()`) から得た多角形 (穴を含む) にグリーンの
    定理ベースの二次モーメント公式を適用したもので、
    `tools/check_head_pod_clearance.py` の grid スキャンとは独立した
    再現可能な計算。UNVERIFIED: PETG曲げ強度70MPaは文献値であり実測では
    ない (既存の全社的な扱いと同じ、安全率で吸収)。Kt=1.5-2.5 も文献の
    チャート読み取りに基づく見積りで実測/FEA ではない。

  **4. `ARM_MOUNT_HUB_Y` 変更**: `hardware/src/config.py` で 12.0→0.0
  (一元定数のため他ファイルは自動追従)。`grep` による悉皆確認で、
  `tools/export_urdf.py` の目サーボ質量アイテム位置に生の literal `12.0`
  が複製されていた (ドリフト穴, `C.ARM_MOUNT_HUB_Y` 参照へ修正) ことと、
  `MOUTH_CANNON_T`/`MOUTH_CANNON_TIP_T` (マウス砲一式のロボット座標,
  Head_Bottom に固定され一緒に動くため hub_y と1:1で並進すべき値) が
  `hub_y=12.0` 時点の絶対座標としてハードコードされたままだった (`hub_y`
  を変えても追従しないドリフト穴) ことの2件を発見・修正した (詳細は
  `hardware/src/config.py` `MOUTH_CANNON_T` 直前のコメント参照)。後者は
  未修正のままだと `tools/check_arm.py [1d]` で `Mouth_Ball` が
  `Head_Bottom_Armcut` と新規に0.28cm³干渉する不具合を引き起こしていた
  (修正後は0.0000cm³で解消)。

  上面図 before/after (`docs/vis_head_center_before_after.png`,
  `tools/render_head_center.py` で当時 [`ARM_MOUNT_HUB_Y=0.0` 時点] に
  生成したもの) で頭部中心=シャーシ中心 (0,0) への移動と `pod_neck`
  頭部側の切り欠き形状を確認できる。**注記 (2026-07-31 QA 再検証)**:
  `tools/render_head_center.py` は `new_hub_y` を `C.ARM_MOUNT_HUB_Y` から
  動的に読む実装のため、現在の `config.py` (`ARM_MOUNT_HUB_Y=11.0`) で
  このスクリプトを再実行すると「AFTER: hub_y=+11.0mm」の図になり、この
  画像 (`hub_y=0.0`) は再現できない — 「再生成可能」は本節作成当時
  (`hub_y=0.0` がまだ `config.py` の値だった時点) の記述であり、現時点の
  参照コマンドとしては使えない。`hub_y=0.0`（不可能と判明した完全中央案）
  と採用値 `hub_y=11.0` の比較を再現したい場合は、下記§7の
  `docs/vis_head_center_sweep3.png` (`tools/render_head_center_sweep.py`
  — hub_y 値を一時的に属性差し替えして複数値を並べて描画するため、
  `config.py` の現在値によらず再現可能) を参照すること。

  **5. `tools/check_head_pod_clearance.py` の基準更新**: 上記2の設計方針
  に合わせ、`pod_neck` から除外域 (基部ブラケットパッドfootprint,
  `HEAD_RELIEF_PROTECT_H`厚み) を差し引いた残り部分についてのみ
  交差0+クリアランス≥2mmを判定するよう改訂した。`hub_y=0` で
  **PASS** (`Head_Bottom`clearance=3.779mm, `Head_Top`clearance=2.706mm。
  2026-07-31 QA 再検証で `HEAD_RELIEF_PROTECT_H` を6.0→8.0mm、
  `CHAMFER_RUN_MM` テーパーを追加した後の値 — 旧値 3.008mm/2.530mm より
  改善している。上記強度検証節参照)。除外域を含めた参考値 (全体交差) も
  併記出力する。

  **6. 発覚した副作用 (完全中央 `hub_y=0.0` は物理的に不可能, 2026-07-31 判明)**:
  `ARM_MOUNT_XY` (腕肩ヨーサーボのシャーシ取付XY) は「頭部の実ソケット直下」
  という設計意図により `ARM_MOUNT_HUB_Y` に連動する式
  (`ARM_MOUNT_XY[1] = ARM_MOUNT_HUB_Y + ARM_MOUNT_R*cos(40°)`) になって
  いる。よって `hub_y` を12→0 に変更すると腕肩ヨーサーボの取付位置も
  シャーシ中心側へ12mm移動し、**前脚 (FR/FL) の股ヨーサーボケースと
  新たに実体干渉する**ことが `tools/check_screw_bosses.py`
  (chassis arm tab fill 47.2%<70%NG) / `tools/check_arm.py`
  ([1] MICRO後側ボスと STD開口の間に肉が残らない, [1b] 肩ブラケットと
  coxa が最大188mm³・クリアランス-2.7mmで実体干渉, [4] 腕作業域が前脚へ
  最大-8mm食い込み) / `tools/check_shin_arm_leg.py`
  ([C]全域グリッドで最大0.8546cm³干渉, ceiling0.08超過でoverall=FAIL) の
  複数の独立した検証で確認された。旧 `hub_y=12` では同じ検証で8.8mm相当の
  クリアランスがあり、**この衝突は今回の中央寄せ変更で新たに生じた副作用**
  である。腕サーボの取付位置は頭部シェル実ソケットの物理位置に追従させる
  必然性があるため (追従させないと腕が頭部シェルの実ソケット穴と噛み合わ
  なくなる)、`pod_neck` 側のカットでは対処できない。

  **7. 境界スイープによる解決 (2026-07-31, 実現可能な最中央値の確定)**:
  「完全中央は物理的に不可能」という上記6の結論を受け、`hub_y ∈ [0,12]`
  を実メッシュで直接スイープし、全チェッカーが緑になる最小の (=最も中央に
  近い) `hub_y` を実測で確定した。スイープは
  `scratchpad/sweep_hub_y.py` (config.py を実際には書き換えず属性を
  実行時差し替えして各チェッカーの中核ロジックを直接呼ぶ高速版) で
  0.5mm刻み・25点を評価し、境界付近は追加で `--wall` オプション (0.05mm
  刻み) と `scratchpad/onset_scan.py` (脚×腕連成クランプの onset を
  腕yaw/pitch/elbow全域で厳密評価) で精密化した。**以下は 2026-07-31 に
  この節を書いたセッションで実際に再実行し、下記の数値をすべて新規に
  確認したもの** (再現手順: 上記2スクリプトを `.venv/bin/python` で実行)。

  **スイープ表** (hub_y 0.0〜12.0mm, 0.5mm刻み。fillA%=chassis arm tab
  ネジ肉充填率の最悪値 [要≥70%] / sepC=`check_arm.py`[1] MICRO後側ボスと
  STD開口の分離 [containment, 要True] / ib_mm3・clr_mm=`check_arm.py`[1b]
  肩ブラケット/upper_arm vs coxa の交差体積・クリアランス [要clr≥1.5mm
  (checker)/≥2mm(選定基準)] / min_d=`check_arm.py`[4] 腕作業域と前脚の
  最小距離 [要>0] / onset_deg=READY代表姿勢での shin_shell干渉開始角,
  参考値・実際のゲート導出は下記onset_scanの全域版を使用):

  | hub_y | fillA% | sepC | ib_mm³ | clr_mm | min_d | onset_deg(参考) |
  |---:|---:|:---:|---:|---:|---:|---:|
  | 0.0 | 47.2 | False | 188.5 | -2.68 | -8.1 | 23.44 |
  | 2.0 | 47.2 | False | 127.0 | -2.37 | -6.4 | 23.84 |
  | 4.0 | 52.3 | False | 43.7 | -1.40 | -4.8 | 24.40 |
  | 6.0 | 59.9 | False | 1.3 | -0.25 | -3.0 | 25.04 |
  | 6.5 | 61.9 | False | 0.0 | 0.03 | -2.5 | 25.20 |
  | 7.5 | 67.0 | False | 0.0 | 0.61 | -1.6 | 25.53 |
  | 8.0 | 69.4 | False | 0.0 | 0.89 | -1.1 | 25.70 |
  | 8.5 | 71.4 | False | 0.0 | 1.18 | -0.6 | 25.87 |
  | 9.0 | 72.6 | False | 0.0 | 1.50 | -0.1 | 26.03 |
  | 9.5 | 72.7 | False | 0.0 | 1.89 | 0.4 | 26.20 |
  | 10.0 | 72.7 | False | 0.0 | 2.33 | 0.8 | 26.37 |
  | 10.5 | 72.7 | True | 0.0 | 2.79 | 1.3 | 26.54 |
  | 11.0 | 72.7 | True | 0.0 | 3.26 | 1.8 | 26.71 |
  | 11.5 | 72.7 | True | 0.0 | 3.73 | 2.3 | 26.88 |
  | 12.0 | 72.7 | True | 0.0 | 4.05 | 2.8 | 27.06 |

  (上表は判読しやすさのため25点中15点を抜粋。sepCがFalse→Trueへ切り替わる
  10.0〜10.5mmの間の精密値は下記 `--wall` スキャン参照)

  **各制約の閾値到達点** (0.5mm格子と `--wall` 精密スキャンから):
  - **fillA≥70%**: hub_y=8.0(69.4%)→8.5(71.4%) の間、補間で **hub_y≈8.2**
  - **[4] min_d>0**: hub_y=9.0(-0.1)→9.5(+0.4) の間、補間で **hub_y≈9.1**
    (旧見積り9.3とほぼ一致。モデル解像度による数mm程度の差は許容)
  - **[1b] clr_mm**: checker閾値 ≥1.5mm は hub_y=9.0 (1.50, ちょうど境界)、
    選定基準 ≥2mm は hub_y=9.5(1.89)→10.0(2.33) の間で **hub_y≈9.8**
  - **[1] 分離 (単一点containment→実肉厚)**: `--wall` 精密スキャン
    (0.05mm刻み) で実測: hub_y=10.30→肉厚0.000mm(境界外側)、
    **10.35→0.021mm(境界通過, knife-edge)**、10.50→0.096mm、
    **10.70→0.196mm**、**11.00→0.346mm**、11.50→0.596mm、12.00→0.846mm
    — 数学的ゼロ交点は **hub_y≈10.305** だが、これは実肉厚ほぼゼロの
    刃先境界でFDM印刷では成立しない。本プロジェクト既存の類似判定
    (`check_screw_bosses.py` の ESP32ボスクリアランス閾値0.3mm) に揃え、
    実肉厚≥0.3mmを満たす最小格子点として **hub_y=11.0 (肉厚0.346mm)**
    を採用の閾値とした
  - **(e) 腕×shin_shell 連成クランプ onset (全域版, `onset_scan.py`
    で2026-07-31再実測)**: hub_y=0.0で **onset=11.00°**、hub_y=11.0で
    **onset=20.03°** (leg reachable集合83点×腕yaw/pitch/elbow全域126点の
    総当り, 0.01cm³しきい値の二分探索)。立位中立ヨー 9.12° (hub_y非依存)
    との margin (onset−neutral) は hub_y=0.0で**1.88°**、hub_y=11.0で
    **10.88°**。hub_y=0.0のonset margin (1.88°) は要求3°未満だったため、
    実際に発火する `ARM_LEG_YAW_GATE_DEG` はonsetよりさらに手前
    (onset直下=10°) に置かざるを得ず、その結果 gate(10°)自体と
    neutral(9.12°)の差はわずか**0.88°**しかなかった (旧構成=中間段階の
    問題点、§4「脚×腕連成クランプ」の発火頻度パラグラフ参照)。
    hub_y=11.0ではonset margin自体が要求3°を大きく上回るため、この
    onset 直下の `ARM_LEG_YAW_GATE_DEG=20.0°` をそのまま採用でき、
    gateとneutralの差も10.88°確保できる (旧 `hub_y=12.0` 時代の実測値と
    ほぼ同値, §「脚×腕連成クランプ」参照)

  **選定**: 上記5条件すべてが要求を満たす最小の hub_y は
  fillA(8.2) < [4](9.1) < [1b](9.8) < **[1](11.0, binding)** の順で、
  **[1] の実肉厚制約が唯一の binding constraint** (他4条件は hub_y=11.0
  時点でいずれも要求を大きく上回る余裕を残す)。よって
  **`ARM_MOUNT_HUB_Y = 11.0mm`** (旧 `12.0` から1mmだけ中央寄せ) を
  実現可能な最中央値として採用した。marginが3°未満になるケースは
  生じなかった (hub_y=11.0で margin=10.88°) ため、次善値の検討は不要
  だった。

  **実装・全検証**: `hardware/src/config.py` `ARM_MOUNT_HUB_Y=0.0→11.0`、
  `firmware/src/config.h` `ARM_MOUNT_Y_MM 37.8f→48.77f`・
  `ARM_LEG_YAW_GATE_DEG 10.0f→20.0f` へ更新。`pod_neck` の頭部逃がしカット
  (`_head_relief_cutter`) は `ARM_MOUNT_HUB_Y` に追従して自動再計算される
  ため、干渉域が縮小した分だけ結果的にカット量が減り (=残存断面が増え)、
  強度の安全率は上記§の `HEAD_RELIEF_PROTECT_H=8.0mm` 設定 (Kt=2.5込み
  実効安全率3.23) に対して**同等以上**になるはずと見積っていたが、
  `hub_y=11.0` 確定後に `tools/check_pod_neck_strength.py`
  (全区間 `σ(y)` スキャンの正本) をこの値で直接再実行して実測確認済み:
  真の最弱点 (`y≈-43.5`, `Z=194.8mm³`, `arm=143.6mm`) はちょうど
  `HEAD_RELIEF_PROTECT_H` の保護域内 (基部側, 相対カット対象が及ばない
  帯) にあり、`hub_y=0`→`11.0` で相対カット量が縮小しても最弱点の断面は
  変化しない (`Z=194.77mm³` で完全一致) — `SF_nominal=8.06`、
  **`Kt=2.5` 込み実効安全率 = 3.23** (要求安全率3を確保, マージン約7.6%)。
  「同等以上」という見積りは的中したが、内訳は「改善した」のではなく
  「最弱点は保護域内にあり hub_y の変化そのものの影響を受けない」だった
  (実測で確認)。
  `build_all.py`→`tools/export_urdf.py`→以下の全チェッカーを本節作成
  セッションで実際に再実行し、すべて PASS/OK であることを確認した。これは
  2026-09-05時点のホスト/静的検査記録であり、現行候補の実機完成・量産解放・
  連続歩行を意味しない。現行の解放境界は `docs/print-first.md` と第2次監査を参照する:
  `check_urdf.py`(380/380 PASS) / `check_screw_bosses.py`(chassis arm tab
  fill 72.7%, OK) / `check_arm.py`([1b]clr 3.3mm・[4]min_d 2mm 含め全OK) /
  `check_shin_arm_leg.py`(overall PASS, [C-duty]発火率 0〜12.7% (速度依存) — 2026-09-04 重心対応スタンス後。旧 42.5-44.2%) /
  `check_head_pod_clearance.py`(clearance 3.779/2.706mm PASS) /
  `check_leg_assembly.py`(worst 0.000cm³ OK) / `check_audio.py`(OK) /
  `check_camera.py`(OK) / `check_eye.py`(OK) / `sim_gait.py`(OK) /
  `pio run`(SUCCESS, Flash 71.7%)。上面図3態比較 (旧12.0/参考0.0/採用11.0)
  は `docs/vis_head_center_sweep3.png` (`tools/render_head_center_sweep.py`
  で再生成可能)。
- **Cabin (ポッド) v3**: ポッドは背中ではなく**後方のネック梁に足と同じ
  高さで接続**する (公式フィギュア準拠)。Cabin_Front 前面下部の内側に
  当て板 (POD_FLANGE 36×30) を接着し、ネック先端フランジと M3×4 で共締め
  (シェル貫通穴 ×4 は現物合わせで開ける — 最小限の加工)。前後シェルは元の
  Cabin_Peg ×2 嵌合を維持。配置は `docs/vis_proportions.png` と実測写真を参照
- Cabin の装飾 (Turret 左右+Peg / RedLight 大小×8 / Spinnarette×4 /
  Cabin_Eye / Insert 全種) は、位置をキット完成写真 (ビルドガイド p.1-3) に
  合わせる設計候補として記録する。現行の今印刷可数は0なので、既存良品の確認と
  印刷解放後に個別判断し、印刷・接着済みとは扱わない。Mouth 一式も同様に
  頭部前面へ配置する候補である。
- **重心確認**: 組立後、実機の対角2脚で持ち上げて姿勢を確認し、バッテリー位置を
  前後調整する。ホスト計算だけで完了とは判定しない。
- **脚×腕連成クランプ (2026-07-31 実装, 同日「腕×脚連成クランプの再導出」
  タスクで hub_y=0 後の最終形状に合わせ数値を再導出)**: 上記「shin_shell
  装飾面の放射外向き確定」タスクで既知不具合として残っていた (a) — 前脚
  (FR/FL) が遊脚で体前方・頭部側へ大きく振れると shin_shell が同側の腕
  (READY 等の前方姿勢) と実体干渉する — を、firmware 側の連成クランプで
  解消した。脚の IK 自体は無制限のまま (歩行を阻害しないため)、危険域では
  同側の腕ヨーだけを最大内寄せ (`-ARM_YAW_LIM`=-15°) へ強制退避させる設計
  (方式自体は再導出後も変更なし)。
  **⚠ 再導出の経緯 (2段階)**: (1) 「頭部中央寄せ」タスクで
  `ARM_MOUNT_HUB_Y` を 12→0 (完全中央) にした際、肩ヨー軸が旧 y≈49.8mm→
  y≈37.8mm へ 12mm 体幹側 (前脚側) へ後退し、旧ゲート `20°` では新形状で
  無対策1.47cm³の干渉を残す状態になったため、一時的に `ARM_LEG_YAW_GATE_
  DEG=10°` へ引き下げていた (中立姿勢9.12°との margin はわずか0.88°で
  発火率70-74%という運用上望ましくない状態だった)。(2) その後「境界
  スイープ (実現可能な最中央値確定)」タスクで `hub_y=0` は
  `check_screw_bosses.py`/`check_arm.py` の静的検査で NG (物理的に不可能)
  と判明し、実測スイープにより `hub_y=11.0` (旧12.0から1mmだけ中央寄せ)
  を採用した (§3「境界スイープによる解決」参照)。この結果、肩ヨー軸の
  後退量が y≈37.8mm→y≈48.77mm (hub_y=0時からほぼ12mm回復、旧12.0時代
  とほぼ同じ配置) となり、gate も再度導出し直す必要が生じた。
  以下は `hub_y=11.0` 確定後に `scratchpad/onset_scan.py`
  (leg reachable集合83点×腕yaw/pitch/elbow全域126点の総当り) で
  2026-07-31 に実測・確認した最終根拠:
  - FR の中立 (静止立位) leg-local yaw は `sim_gait.leg_ik()` 実測で
    約 +9.12° (`hub_y` に非依存の脚側パラメータのみで決まるため不変)
  - クランプ非発火時 (腕 yaw/pitch/elbow 全域, 脚 pitch/knee 到達可能集合
    全域) の shin_shell 干渉は、hub_y=11.0 では FR yaw=17.5°まで常に
    0.0000cm³ (中立姿勢9.12°を含め大きな安全マージンあり)、yaw=20.0°で
    0.0023cm³ (実質ゼロ)、yaw=25.0°で1.3305cm³、yaw=30°で4.8404cm³ —
    onset (0.01cm³しきい値の二分探索) は **20.03°**。比較として
    hub_y=0.0 では同じ手法で onset=**11.00°** (旧「10-12.5°」という粗い
    見積りと整合) だった。**新ゲート `ARM_LEG_YAW_GATE_DEG=20.0°`**
    (onset直下, 旧`hub_y=12.0`時代と同じ値) は中立姿勢9.12°との margin
    **10.88°** を確保する (旧hub_y=0/gate=10°時代のmargin 0.88°から
    大幅に改善)
  - 腕側の退避は従来どおりヨーだけで足りる (pitch/elbow は無関係)。
    `check_shin_arm_leg.py` [C]/[C-duty] の実チェッカーで新ゲート適用後の
    全域グリッドがceiling(0.25cm³)内に収まることを確認済み (PASS, 詳細は
    下記発火頻度パラグラフのチェッカー実行結果参照)
  - FL(左脚)+左腕は FR+右腕の左右鏡像 (shin_shell/腕とも X ミラー構成) で、
    数値が厳密に一致する (危険方向の yaw 符号だけが反転,
    `ARM_LEG_YAW_SIGN={+1,-1}`, 変更なし)
  実装: `firmware/src/arms.h` の `Arms::update()` が呼び出し側 (`main.cpp`)
  から当該フレームの前脚関節角 (`legAng[0]`=FR相当, `[1]`=FL相当) を受け取り、
  同側脚が危険域なら腕ヨーを target/cur_ (スルーレート後) の両方で
  `-ARM_YAW_LIM` へ強制する (「目標側だけのクランプは独立スルー軸がある
  遷移で必ず破れる」という本プロジェクト既知の教訓に従い2段で適用)。
  検証: `tools/check_shin_arm_leg.py` [C] を拡張し、firmware のクランプ式を
  config.h から regex 読取で複製した上で、クランプ通過後に到達可能な
  全姿勢集合 (FR脚 yaw全域×pitch/knee 到達可能集合×腕 pitch/elbow 全域,
  危険域のみ) で実メッシュ干渉が0.25cm³ (既知許容残留 0.166cm³ に余裕を
  持たせた ceiling) 未満であることを確認済み (PASS)。**再導出タスクで
  [C] の全域グリッド判定も [B] (shin-shin/tibia-tibia) と同じ
  `pk_reachable()` (firmware到達可能集合) 基準に統一した** — 旧判定は
  (leg_pitch,leg_knee) を絞り込まずに評価しており、gait.h ワークスペース
  射影の不動点条件を満たさず歩容コマンドとして出力され得ない組合せ
  (worst=0.8546cm³) を誤って算入していたため。Web UI は腕ヨースライダーの
  範囲が既に ±15° (=`ARM_YAW_LIM`) と一致しており、クランプ発火時に
  スライダー値自体を書き換える必要はない (地面ガード等の既存クランプと
  同じ「無言で出力だけ retreat する」挙動を踏襲、UI側の追随実装は不要と
  判断)。
  **クランプの発火頻度 (2026-07-31 境界スイープタスクで最終確定, 詳細は
  §4)**: `hub_y=11.0`/ゲート20.0°の組合せで `tools/check_shin_arm_leg.py`
  [C-duty] を本節作成セッションで実際に再実行し、通常の前進歩行中
  (前進速度 vx=0.1〜1.0, 各600サンプル) に発火する時間比率を実測した結果
  **42.5%〜44.2%** (ほぼ速度非依存) だった (**2026-09-04 の重心対応スタンス STANCE_OFF_Y -30 後は
  0%〜12.7% で速度依存** — 低速ではほぼ発火せず最大速度で 12.7%。監視レンジは「最大速度で 25% 未満」に変更) — 中間段階の
  `hub_y=0`/ゲート10°時代の70-74%から大幅に低下し、旧`hub_y=12.0`時代の
  42-44%相当の水準にほぼ完全に復帰した (肩ヨー軸の後退量が
  hub_y=0時のほぼ12mmからhub_y=11.0では実質1mm相当まで縮小したことの
  直接的な帰結)。歩容周期 `CYCLE_T=1.6秒` のうち約0.68〜0.71秒が該当し、
  「前方へ大きく振れる瞬間限定」という従来の説明が改めて妥当になった。
  `tools/check_shin_arm_leg.py` [C-duty] がこの発火時間比率を毎回実測・
  回帰監視する (想定レンジは42-44%近辺へ復帰、下記§4の表も参照)。

## 4. 歩行調整

1. Web UI の Trim 画面で脚 13ch + 腕 8ch + 目 2ch (左右のみ。中央は固定
   カメラ目でサーボ無し) のセンター微調整 (足先が正方形の四隅、腕は
   TUCK 姿勢で左右対称、目は瞳が真下)
2. 逆に動く関節があれば `config.h` の `JOINT_SIGN` (脚) / `ARM_SIGN` (腕) の
   該当エントリを反転 (v3: FR/RL はミラー脚なのでピッチ/膝の初期値が -1。
   標準脚 FL/RR と鏡向きに動くのが正しい)
3. 体高 115mm・歩幅 50% から開始、安定したら上げる。歩行中の腕は TUCK 推奨
   (肩ピッチに ±8° のスイングが自動で乗る)
4. フローリングで滑る場合は foot_pad (TPU) の硬度/接地径を調整

## 参考: 関節可動域 (設計値, 検証済み)

| 関節 | 範囲 | 備考 |
|---|---|---|
| 股ヨー | ±40° | ソフトリミット (v3: 前脚が腕から離れたため ±35→±40 に緩和)。**追加クランプ**: 45°ペア (FR↔RR, FL↔RL) の内側は単側 ±17.5°・同時和 ≤26°、後脚のポッド側は ±30° (2026-09-04 22→30。実メッシュ掃引で接触開始 34°) (全て実メッシュ検証値。深タック姿勢の手ポーズで隣接脚を同時に内側へ向けないこと) |
| 股ピッチ | -45°(上げ)〜+55°(下げ) | スプロール立位の定常値は約 -16° (体高115) |
| 膝 | ±44° | 機構限界 45° の手前。サーボ実体込みで干渉ゼロ確認済 |
| 肩ヨー | ±15° (中立向きからの追加, 常時) | 2026-07-28 実ソケット移設: 中立 (ヨー0) は正面から**放射外向き 40°** (`ARM_MOUNT_YAW_DEG`, Head_Bottom ソケット実測)。前脚 (mount 15°) との角度差 35° が新たな最接近。2026-07-31 境界スイープタスクで `ARM_MOUNT_HUB_Y` が0.0→11.0 (旧12.0から1mm中央寄せ) に確定した最終形状で実メッシュ掃引を再実行した結果、ヨー+15°×脚ヨー+40° の肩ブラケット/上腕vscoxaクリアランス **3.3mm** (`check_arm.py` [1b], 要求1.5mm以上でOK) を確認 (粗近似モデルの [4] は同条件下で腕作業域と前脚の最小距離2mm相当と保守的に出るが実メッシュで裏取り済み)。折り畳み姿勢 (planar<-5) はヨー0固定に加え、ピッチを起こして planar の深追いを防ぐガードが別途入る (放射マウント固有, 2026-07-28 追加) |
| 肩ピッチ | -45°(上げ)〜+85°(下げ) | 0° = 上腕が中立ヨー方向 (放射外向き40°) に水平。腕は Head_Bottom ソケットから吊り下げ |
| 肘 | 0°(伸ばし)〜95°(曲げ) | サーボ中立 = 45° 曲げ |

2026-07-29 固定爪化によりグリップ軸 (旧サブマイクロ駆動, 0(開)〜60(閉)) は
廃止。手は爪ハブ (Arm_Left_Claw_Grey) + 指 (Arm_Left_Finger_Black_x3) + 指先
チップ (Arm_Left_FingerTip_Grey_x3) を claw_mount へ接着した受動パーツで、
片腕あたりのサーボは肩ヨー/肩ピッチ/肘の 3 個のみ (ch 19/23 の旧グリップ
チャンネルは未使用のまま予約)。

- **地面ガード**: 手先が床へ潜る指令はファームがピッチを起こして寸止めする
  (体高指令に連動)。v3 のキット比率短縮で腕は床に届かない (PICK 廃止)
- 内側ヨーは両腕接触回避のため手先中心 x が ~14mm (HAND_HALF=14.5mm, 2026-07-29
  固定爪化で旧「パーム半径13.5」から根拠を入替え — 実メッシュの爪+指+指先
  チップ一体の局所横幅実測 14.30mm を安全側で上回る値、`check_arm.py` [5b]
  参照) を割らないよう自動制限。放射マウント (中立ヨーが正面から40°外向き) では中立姿勢の時点で手先が大きく外側にあるため、旧来の前向き中立マウントよりこの相互クランプは発火しにくい (`check_arm.py` [5] 実測: クランプ適用後の手先中心 x 最小値 28.5mm — 旧マウントの基準値 ~14mm より大幅に余裕)。折り畳み姿勢はヨー 0 固定 + ピッチガードの併用
- **脚×腕連成クランプ (2026-07-31 追加。同日中に2段階の再導出を経て
  `ARM_LEG_YAW_GATE_DEG` は最終的に `20.0°` — 経緯は §3「脚×腕連成
  クランプ」参照)**: 前脚 (FR/FL) が遊脚で体前方・頭部側へ大きく振れる
  (脚 yaw が中立から+側に大きい, 実歩容で発生) と shin_shell が同側の腕
  (READY 等) と実体干渉するため、firmware が同側脚 yaw が閾値
  (`ARM_LEG_YAW_GATE_DEG=20°`) を超えたら該当腕のヨーを自動的に最大内寄せ
  (-15°) へ退避させる (脚側の IK は制限しない — 歩行を優先)。
  **発火頻度の実測値 (2026-07-31 境界スイープタスクで最終確定)**:
  「頭部中央寄せ」タスクで一時的に `hub_y=0`/ゲート`10°`とした際は
  onset角度が~22.5-25°から10-12.5°へ前倒しし、発火率が69.7%〜73.5%まで
  悪化していた。その後の「境界スイープ (実現可能な最中央値確定)」タスクで
  `hub_y=0`は物理的に不可能と判明し `hub_y=11.0`(旧12.0からわずか1mmの
  中央寄せ)を採用したことで、肩ヨー軸の後退量が実質1mm相当まで縮小し、
  onset (全域探索, `scratchpad/onset_scan.py`) は **20.03°** まで回復
  (旧`hub_y=12.0`時代の実測とほぼ同値)。新ゲート `20.0°` を採用のうえ
  `sim_gait.py` の実歩容ロジックで前進歩行中の FR 脚 yaw を実際に
  時間発展させて `tools/check_shin_arm_leg.py` [C-duty] で実測すると、
  前進速度 (vx=0.1〜1.0) を振っても、ゲート閾値を超える時間比率は
  **42.5%〜44.2%** (600サンプル/速度点, ほぼ速度非依存) — 中間段階の
  70%台から大幅に改善し、旧`hub_y=12.0`時代 (42-44%) にほぼ完全復帰した。
  歩容周期 `CYCLE_T=1.6秒` のうち約0.68〜0.71秒が該当し、「前方へ大きく
  振れる瞬間限定」で腕が内寄せ退避する — 従来の想定どおりの、常態的では
  ない挙動になっている。さらに `sim_gait.leg_ik()` 実測では静止立位
  (歩行していない, sway=0) の FR 中立ヨーは約 **+9.12°** (`hub_y`非依存)
  であり、新ゲート `20.0°` との margin は **10.88°** (要求3°を大きく
  上回る) — 静止立位はもちろん、通常の歩容の大半でもゲート未満のまま
  推移する。実運用上の含意: (1) READY 等でユーザーが任意のヨー姿勢を
  保持していても、通常歩行中の約42-44%の時間 (前方へ大きく踏み出す瞬間)
  だけ無言で-15°へ引き戻される、(2) 歩行中に WAVE (肘/ヨーを振る
  バイバイ) を実行しても、破綻するのは全体の半分未満の時間帯に限られる、
  (3) 静止姿勢 (READY/TUCK/WAVE を歩行させずに使う分) には影響しない。
  メッシュ干渉自体はクランプ後 0〜0.166cm³ で安全 (ceiling=0.25cm³ 以下)。
  実測・回帰監視は `tools/check_shin_arm_leg.py` [C-duty] (想定レンジ
  最大速度で 25% 未満 (2026-09-04 更新), 実測 0-12.7% は範囲内) を参照。
  詳細・干渉体積の実測根拠は §3「脚×腕連成クランプ」参照

体高 110〜130mm (2026-09-04 下限 105→110)。歩容は回転順クロール (RL→FL→FR→RR) +
重心シフト 前脚 34 / 後脚 40mm + 中立足先パターンを実重心側へ 30mm オフセット
(`STANCE_OFF_Y`)。中立スタンスは前脚 +18°/後脚 -2° の非対称 (公式フィギュアのポーズ準拠)。
実重心 (`config.py CG_XY` y=-39mm, Cabin が主因) 基準の静的安定マージンは +10.9mm
(旧記載 +8.8mm は重心=原点の誤仮定, `sim_gait.py` [4] 参照)。
腕プリセット: TUCK (収納) / READY (構え) / REACH (前方) / WAVE (バイバイ)。

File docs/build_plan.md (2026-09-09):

# 物理製作 ビルドプラン — Issue駆動で複数人が並行するための全体図

作成 2026-09-03。計画の正は [`tools/issues/plan.py`](../tools/issues/plan.py)、
GitHub Issues への同期は [`tools/issues/sync_github_issues.py`](../tools/issues/sync_github_issues.py)、
作業の取り方は [`CONTRIBUTING.md`](../CONTRIBUTING.md)、
ボードは [GitHub Project「Tachikoma 物理製作」](https://github.com/users/hapx2yuki/projects/2) (Public)。
2026-08-31 の「調達済み・一部印刷済み」は過去の申告。2026-09-05 に Amazon の注文履歴を照合し、購入数量・配達状態・現物確認を分けて [追加購入一覧](additional-purchases.md) に記録した。印刷済み数量は [全99 STL の台帳](additional-printing.md) で現物照合待ち。

**2026-09-05 更新:** [第2次監査](audits/20260905-round2/README.md) に基づき、E9で修正を管理。
全96課題を個別に見直した [現在地・次作業・依存の理由](issues-audit-20260905.md) を参照。
片脚用tibia (`PR-04`) → 片脚合格 (`L-02`) → 残り3本 (`PR-11`) の順。
トルク/電源対策は試験の失敗時にも着手できるよう合格待ち依存を外した。
フルドレス歩行 (`I-02`) は足裏支持 (`RV-06`) と印刷物強度 (`RV-07`) の確認後に行う。
自動生成された依存と `plan.py` を正とする。

## 1. 構造 (2 軸 + 依存)

- **マイルストーン = いつ (Go/No-Go ゲート)**
  `M0 準備完了` → `M1 片脚 Go/No-Go` (1.2kg リフト) → `M2 頭無し歩行` → `M3 サブアセンブリ` → `M4 フルドレス` → `M5 統合・完成`
- **エピック = 何の流れ (作業ストリーム, サブイシューで束ねる)**
  `E1 準備` / `E2 印刷キュー` / `E3 電装・ファーム` / `E4 脚・歩行` / `E5 腕` / `E6 頭部 (目・カメラ・音声)` / `E7 意匠シェル・Cabin` / `E8 統合` / `E9 独立監査`
- **依存 = 順番** — GitHub の blocked by / blocking。`is:open -is:blocked` で「今できること」が出る
- **占有リソース** — `res/プリンタ` (X2D 1 台 = 印刷は 1 本のキュー) / `res/本体` (シャーシ組立品)。それ以外は `並行作業OK`

## 2. 同時に進める作業と順序を守る作業

| 独立に進められる作業 | 次へ進む条件 |
|---|---|
| P-01/P-03: 購入型番・サーボ寸法/角度の照合 | P-04へ実測値を渡す。未確認の型番を設計値と同一視しない |
| P-02: 印刷済み品と使用3MFの照合 | 既印刷品を保存し、P-05で再利用・加工・再印刷を部品ごとに判断 |
| RV-08: 音声、RV-09: 頭部、RV-10: 腕脚、H-06: Cabin | 共通の配置/配線/荷重面を先に合意し、部位ソースを分担する |
| RV-11/EL-09/L-11: 電源・必要トルクの調査と対策 | 歩行/片脚試験の合格待ちにしない。失敗ログも対策の入力にする |
| RV-01/RV-12: 制御・表示の整合 | 実firmwareの出力を物理計算へ渡し、表示だけの動作を実証としない |

設計変更後は **STL再生成 → URDF再生成 → 全検証 → 対象3MF作成** の順で一人が統合する。
同じ出力を複数担当が同時に生成しない。プリンタは1台なので、試験用の片脚を優先して順に使う。
**PR-04の標準tibia1本 → L-02の片脚試験 → PR-11の残り3本** が脚の印刷順。
RV-09の取付軸確定 → RV-13頭固定/RV-14脚カバーの順。RV-15首/CabinはH-06電装室と境界を合わせ、同じmake_chassis.pyを同時編集しない。
H-06の内部室/着脱保持とRV-15全接合が成立する前にCabinを接着して閉じない。
RV-16のガード受け座とRV-17の固定手は局所形状の検討を並行できる。全身の軸配置へ影響する寸法はRV-09/10/14と共有し、実部品の接着は両課題の検証後とする。
フルドレス歩行I-02はRV-06の足裏支持とRV-07の印刷物強度の確認後に行う。

## 3. 担当の分け方

CAD担当はファイルの所有範囲をIssueへ書く。電装担当は型番/電圧/配線図と測定条件、
印刷担当は使用3MFのハッシュ・材質・向き・壁数、実機試験担当は動画と計測値を残す。
共有config.pyとSTL出力を変更するときは統合担当へ引き渡す。
`並行作業OK`は他Issueとの共有ファイル競合や依存を解除する意味ではない。

## 4. 現時点の製作条件

- H-06: Cabin電装室・棚・Backの保持/配線を検査してからS-05へ渡す。
- RV-09/H-02: 頭部の実ケース収納とXIAO/カメラ/FPCが成立してから頭部印刷・接着。
- P-05: 購入済みサーボ・印刷済み品に合わせ、再利用可能な部品を優先する。
- H-07: CH_HEADは予約専用・PWM停止を実装。実機でch12が停止していることを確認。
- S-08: Head_Insert_Blackの未確定2個は元写真/実物で確認する。
- L-09: 機体を支持して起動し、明示的な立位操作で通電。USBと外部5Vを同時接続しない。

## 5. 自動生成部 (依存グラフ・一覧)

以下は `sync_github_issues.py --plan-doc` が `issue_map.json` から生成する。手で編集しない。

<!-- BEGIN GENERATED (tools/issues/sync_github_issues.py --plan-doc) -->
_生成: 2026-09-05 / イシュー数 96 / 依存 156_

### 依存グラフ (矢印 = 先行 → 後続。エピックは省略)

```mermaid
flowchart LR
  subgraph E1["E1 準備"]
    P_01["P-01 購入部品の棚卸し・検品"]
    P_02["P-02 印刷済みパーツの棚卸し・検品・ラベリング"]
    P_03["P-03 サーボ・ホーン実測"]
    P_04["P-04 実サーボ寸法を設定へ反映し、再生成・退行検査・印刷影響を"]
    P_05[/"P-05 印刷済み品を部品別に再使用・内部加工・補強・再印刷へ分け"/]
    P_06["P-06 音声ユニット部品の実測"]
    P_07["P-07 カメラモジュール確認"]
    P_08["P-08 イシュー運用の立ち上げ"]
  end
  subgraph E2["E2 印刷キュー"]
    PR_01["PR-01 キット灰意匠を不足・嵌合条件別に分離して印刷する"]
    PR_02["PR-02 黒いトゥ・指・Insertを部品別の確定条件で印刷する"]
    PR_03["PR-03 赤ランプ大4・小4の不足分を透光試験後に用意する"]
    PR_04["PR-04 片脚試験用の標準 tibia_link ×1 を先に印刷"]
    PR_05["PR-05 足本体と大腿カバーを別条件で試作・不足数印刷する"]
    PR_06["PR-06 首・腕・目・カメラ・音声受けを個別条件で引き渡す"]
    PR_07["PR-07 Mouth_Cannon_Bored + Mouth_B"]
    PR_08["PR-08 頭の収納・支持確定後にHeadTopの再使用か改訂印刷を"]
    PR_09["PR-09 (条件付き) 骨格の再印刷 — P-05 で「再印刷」と"]
    PR_10["PR-10 実カメラ版に合うbase・shell・carrierを1"]
    PR_11["PR-11 片脚合格後に残りのtibiaを標準1本・ミラー2本印刷す"]
  end
  subgraph E3["E3 電装・電源・ファームウェア"]
    EL_01["EL-01 電源系ベンチ組立"]
    EL_02["EL-02 PCA9685 ×2 準備"]
    EL_03["EL-03 CALIBRATION_MODE ビルド + ESP32"]
    EL_04["EL-04 実サーボを1個ずつ校正し、20駆動軸と予備を識別する"]
    EL_05["EL-05 脚サーボハーネス ×12 製作"]
    EL_06["EL-06 腕・目サーボハーネス製作"]
    EL_07["EL-07 通常版を無負荷ベンチで確認し、初期脱力・出力方向を検証す"]
    EL_08["EL-08 WS2812 ×12 + 74AHCT125 + DFP"]
    EL_09[/"EL-09 実電源の電圧・電流・温度から継続か交換を決める"/]
    EL_10["EL-10 アイドル時の発熱対策"]
    RV_11["RV-11 部品の実型番・電源収支・停止回路・測定手順を整合させる"]
  end
  subgraph E4["E4 脚・歩行"]
    L_01["L-01 脚 FL"]
    L_02{{"L-02 片脚ベンチ試験"}}
    L_03["L-03 脚 FR"]
    L_04["L-04 脚 RL"]
    L_05["L-05 脚 RR"]
    L_06["L-06 頭無し試験用シャーシ・ヨーサーボ・仮電装を組む"]
    L_07["L-07 4 脚をシャーシへ取付"]
    L_08["L-08 脚 12ch 本体配線"]
    L_09["L-09 通電・中立確認・トリム"]
    L_10{{"L-10 頭無し歩行試験"}}
    L_11[/"L-11 股ピッチの実力を測り、低トルク歩容・軽量化・6V対応品を"/]
    RV_06["RV-06 トゥと硬い足本体の先行接地を解消して足裏支持を成立させる"]
    RV_14["RV-14 シャーシと大腿カバーの実交差を解消する"]
  end
  subgraph E5["E5 腕"]
    A_01["A-01 右腕チェーンをベンチで組む"]
    A_02["A-02 左腕チェーンをベンチで組む"]
    A_03["A-03 肩ヨーサーボ ×2 をシャーシへ + 両腕を吊り下げ +"]
    A_04["A-04 腕殻の改訂配置とGuard原型・左右対応を確認して固定す"]
    RV_10["RV-10 肩と前脚のケース干渉・腕Guardの原型対応を解消する"]
    RV_17["RV-17 固定爪・指・指飾りの嵌合公差と接着座を検証する"]
  end
  subgraph E6["E6 頭部"]
    H_01["H-01 目ポッド ×2"]
    H_02["H-02 カメラ目"]
    H_03["H-03 音声ユニット組込"]
    H_04["H-04 裸配線のI2S音声をmock・PTT・低音量再生でベンチ"]
    H_05["H-05 改訂Mouth一式の挿入・小キー公差・配線を確認する"]
    H_06["H-06 Cabin内部の電装室・基板保持・挿入経路・配線を成立さ"]
    H_07[/"H-07 CH_HEAD/ch12を予備・未接続として実物確認する"/]
    RV_08["RV-08 修正済みMouth挿入路に残る小キー公差・実保持を確定す"]
  end
  subgraph E7["E7 意匠シェル・Cabin・仕上げ"]
    S_01["S-01 pod_neck 取付 + TailJoint"]
    S_02a["S-02a 脚 FL の装飾"]
    S_02b["S-02b 脚 FR の装飾"]
    S_02c["S-02c 脚 RL の装飾"]
    S_02d["S-02d 脚 RR の装飾"]
    S_03["S-03 頭部組立"]
    S_04["S-04 Mouth 一式を頭部ソケットへ取付"]
    S_05["S-05 Cabinの電装室・接合・目座が確定した部品を組む"]
    S_06["S-06 採用した首とCabinの支持・締結・通線を実物で確認する"]
    S_07["S-07 LED ×12 / DFPlayer / 74AHCT1"]
    S_08[/"S-08 頭Insert・Screwの位置と受け座・挿入経路を照合"/]
    RV_07{{"RV-07 実際の壁数・充填率による脚とポッド支持の強度を確かめる"}}
    RV_09["RV-09 頭部内の実サーボケースとポッド梁の干渉を解消する"]
    RV_13["RV-13 頭の7固定穴から外殻へ届く支持柱・受け座を設計する"]
    RV_15["RV-15 首・Cabin・装飾を全長で組み合わせ、支持と挿入を成立"]
    RV_16["RV-16 大腿・脛ガードの受け座と実際に入る組立経路を作る"]
  end
  subgraph E8["E8 統合・調整・完成"]
    I_01["I-01 全装備の実重量・支持荷重・重心を測りモデルへ反映する"]
    I_02["I-02 フルドレス歩行調整"]
    I_03["I-03 音声会話の実運用"]
    I_04["I-04 カメラ連携"]
    I_05["I-05 演出確認"]
    I_06["I-06 組立で得た現物合わせ知見を docs へ反映"]
    I_08["I-08 実購入個体の照合後に物理モデル・自己干渉・材料別接触を再"]
    I_07["I-07 完成お披露目"]
  end
  subgraph E9["E9 実機製作前提を独立検証し、修正と実機確認を切り分ける"]
    RV_01["RV-01 操作画面・低電圧停止・腕脚ガードを修正して回帰検証する"]
    RV_02["RV-02 現物3MFの形状・数量・材質と再生成時の保持を検査する"]
    RV_03["RV-03 幾何・歩容検査のNGと計算失敗を終了コードへ反映する"]
    RV_04["RV-04 Issue同期で進捗を保持し、重複と依存関係を検証する"]
    RV_05{{"RV-05 修正後の全検証と未確認の実機条件を記録する"}}
    RV_12["RV-12 表示用モデルと全ファイルの検査記録を実設計に合わせる"]
  end
  P_03 --> P_04
  P_04 --> P_05
  P_02 --> P_05
  P_02 --> PR_01
  P_02 --> PR_02
  P_02 --> PR_03
  P_04 --> PR_04
  P_05 --> PR_04
  P_04 --> PR_05
  P_04 --> PR_06
  P_06 --> PR_07
  RV_08 --> PR_07
  P_02 --> PR_08
  RV_09 --> PR_08
  RV_13 --> PR_08
  P_05 --> PR_09
  P_07 --> PR_10
  P_02 --> PR_10
  EL_01 --> EL_04
  EL_02 --> EL_04
  EL_03 --> EL_04
  P_03 --> EL_04
  EL_03 --> EL_07
  EL_07 --> EL_08
  PR_04 --> L_01
  EL_04 --> L_01
  P_05 --> L_01
  L_01 --> L_02
  EL_01 --> L_02
  EL_03 --> L_02
  L_02 --> L_03
  PR_11 --> L_03
  L_02 --> L_04
  PR_11 --> L_04
  L_02 --> L_05
  PR_11 --> L_05
  EL_01 --> L_06
  EL_02 --> L_06
  EL_04 --> L_06
  P_05 --> L_06
  L_01 --> L_07
  L_03 --> L_07
  L_04 --> L_07
  L_05 --> L_07
  L_06 --> L_07
  L_07 --> L_08
  EL_05 --> L_08
  L_08 --> L_09
  EL_07 --> L_09
  L_09 --> L_10
  EL_07 --> EL_10
  EL_04 --> A_01
  P_04 --> A_01
  RV_17 --> A_01
  EL_04 --> A_02
  P_04 --> A_02
  RV_17 --> A_02
  A_01 --> A_03
  A_02 --> A_03
  L_07 --> A_03
  EL_06 --> A_03
  EL_07 --> A_03
  RV_09 --> A_03
  RV_10 --> A_03
  A_03 --> A_04
  EL_04 --> H_01
  P_04 --> H_01
  P_07 --> H_02
  PR_10 --> H_02
  PR_07 --> H_03
  P_02 --> H_03
  RV_08 --> H_03
  EL_07 --> H_04
  H_03 --> H_05
  RV_08 --> H_05
  L_06 --> S_01
  RV_15 --> S_01
  RV_07 --> S_01
  L_10 --> S_02a
  RV_06 --> S_02a
  RV_14 --> S_02a
  RV_16 --> S_02a
  L_10 --> S_02b
  RV_06 --> S_02b
  RV_14 --> S_02b
  RV_16 --> S_02b
  L_10 --> S_02c
  RV_06 --> S_02c
  RV_14 --> S_02c
  RV_16 --> S_02c
  L_10 --> S_02d
  RV_06 --> S_02d
  RV_14 --> S_02d
  RV_16 --> S_02d
  H_01 --> S_03
  H_02 --> S_03
  H_06 --> S_03
  PR_08 --> S_03
  L_10 --> S_03
  RV_09 --> S_03
  RV_13 --> S_03
  S_08 --> S_03
  H_05 --> S_04
  S_03 --> S_04
  H_06 --> S_05
  RV_15 --> S_05
  S_05 --> S_06
  S_01 --> S_06
  EL_08 --> S_07
  S_03 --> S_07
  S_06 --> S_07
  S_03 --> I_01
  S_04 --> I_01
  S_06 --> I_01
  S_07 --> I_01
  A_04 --> I_01
  S_02a --> I_01
  S_02b --> I_01
  S_02c --> I_01
  S_02d --> I_01
  I_01 --> I_02
  L_10 --> I_02
  I_08 --> I_02
  RV_06 --> I_02
  RV_07 --> I_02
  H_04 --> I_03
  H_02 --> I_04
  I_03 --> I_04
  S_07 --> I_05
  I_02 --> I_05
  I_02 --> I_07
  I_03 --> I_07
  I_04 --> I_07
  I_05 --> I_07
  I_06 --> I_07
  L_02 --> PR_11
  RV_01 --> RV_05
  RV_02 --> RV_05
  RV_03 --> RV_05
  RV_04 --> RV_05
  I_08 --> RV_05
  RV_06 --> RV_05
  RV_07 --> RV_05
  RV_08 --> RV_05
  RV_09 --> RV_05
  RV_10 --> RV_05
  RV_11 --> RV_05
  RV_12 --> RV_05
  RV_13 --> RV_05
  RV_14 --> RV_05
  RV_15 --> RV_05
  RV_16 --> RV_05
  RV_17 --> RV_05
  H_06 --> RV_05
  RV_09 --> RV_13
  RV_09 --> RV_14
  classDef gate fill:#ffd6d6,stroke:#b60205,stroke-width:2px;
  class L_02,L_10,RV_05,RV_07 gate;
  classDef dec fill:#fff3bf,stroke:#fbca04;
  class P_05,EL_09,L_11,H_07,S_08 dec;
```

### 今すぐ着手できるイシュー (依存なし)

- #11 P-01 [運営] 購入部品の棚卸し・検品 (BOM / shopping.md D-1 と照合)  ← 並行作業OK
- #12 P-02 [運営] 印刷済みパーツの棚卸し・検品・ラベリング (旧 rev 混入チェック)  ← 並行作業OK
- #13 P-03 [測定] サーボ・ホーン実測 (STD ×14 / MG90S ×6 / ES9251II ×3) → 実測表  ← 並行作業OK
- #16 P-06 [測定] 音声ユニット部品の実測 (INMP441 基板 / φ20 SPK 厚) → AUDIO_* 更新 → check_audio  ← 並行作業OK
- #17 P-07 [測定] カメラモジュール確認 (XIAO ESP32S3 Sense: センサー型番・子基板寸法・FOV) → CAM2_* 更新 → check_camera  ← 並行作業OK
- #18 P-08 [運営] イシュー運用の立ち上げ (CONTRIBUTING / テンプレ / Project ボード / 協力者招待)
- #28 EL-01 [電装] 電源系ベンチ組立 (LiPo→ヒューズ→SW→UBEC 6V / DC-DC 5V, バスバー, コンデンサ, 分圧)  ← 並行作業OK
- #29 EL-02 [電装] PCA9685 ×2 準備 (board1 A0 ジャンパ→0x41, ヘッダ実装規約) + ESP32 I2C 疎通  ← 並行作業OK
- #30 EL-03 [ファーム] CALIBRATION_MODE ビルド + ESP32 書き込み + AP 接続確認  ← 並行作業OK
- #32 EL-05 [配線] 脚サーボハーネス ×12 製作 (電源 AWG20→AWG16 バス分岐 / 信号 AWG26→PCA)  ← 並行作業OK
- #33 EL-06 [配線] 腕・目サーボハーネス製作 (MG90S ×6 / ES9251II ×2, AWG26/30)  ← 並行作業OK
- #75 EL-09 [要判断] 実電源の電圧・電流・温度から継続か交換を決める
- #77 L-11 [要判断] 股ピッチの実力を測り、低トルク歩容・軽量化・6V対応品を比較する
- #55 H-06 [CAD] Cabin内部の電装室・基板保持・挿入経路・配線を成立させる  ← 並行作業OK
- #56 H-07 [要判断] CH_HEAD/ch12を予備・未接続として実物確認する
- #67 S-08 [要判断] 頭Insert・Screwの位置と受け座・挿入経路を照合する
- #73 I-06 [ドキュメント] 組立で得た現物合わせ知見を docs へ反映 (assembly / wiring / print_manifest / HANDOFF)  ← 並行作業OK
- #78 I-08 [検証] 実購入個体の照合後に物理モデル・自己干渉・材料別接触を再評価する  ← 並行作業OK
- #81 RV-01 [不具合] 操作画面・低電圧停止・腕脚ガードを修正して回帰検証する  ← 並行作業OK
- #82 RV-02 [検証] 現物3MFの形状・数量・材質と再生成時の保持を検査する  ← 並行作業OK
- #83 RV-03 [不具合] 幾何・歩容検査のNGと計算失敗を終了コードへ反映する
- #84 RV-04 [不具合] Issue同期で進捗を保持し、重複と依存関係を検証する  ← 並行作業OK
- #87 RV-06 [機構不具合] トゥと硬い足本体の先行接地を解消して足裏支持を成立させる
- #88 RV-07 [試験] 実際の壁数・充填率による脚とポッド支持の強度を確かめる
- #89 RV-08 [機構不具合] 修正済みMouth挿入路に残る小キー公差・実保持を確定する  ← 並行作業OK
- #90 RV-09 [機構不具合] 頭部内の実サーボケースとポッド梁の干渉を解消する  ← 並行作業OK
- #91 RV-10 [機構不具合] 肩と前脚のケース干渉・腕Guardの原型対応を解消する  ← 並行作業OK
- #92 RV-11 [電装] 部品の実型番・電源収支・停止回路・測定手順を整合させる  ← 並行作業OK
- #93 RV-12 [検証] 表示用モデルと全ファイルの検査記録を実設計に合わせる  ← 並行作業OK
- #96 RV-15 [機構不具合] 首・Cabin・装飾を全長で組み合わせ、支持と挿入を成立させる  ← 並行作業OK
- #97 RV-16 [機構不具合] 大腿・脛ガードの受け座と実際に入る組立経路を作る  ← 並行作業OK
- #98 RV-17 [機構不具合] 固定爪・指・指飾りの嵌合公差と接着座を検証する  ← 並行作業OK

### 一覧 (マイルストーン順)

| key | イシュー | マイルストーン | 前提 | 並行 |
|---|---|---|---|---|
| EL-01 | #28 EL-01 [電装] 電源系ベンチ組立 (LiPo→ヒューズ→SW→UBEC 6V / DC-DC 5V, バスバー, コンデンサ, 分圧) | M0 準備完了 | — | ✅ |
| EL-02 | #29 EL-02 [電装] PCA9685 ×2 準備 (board1 A0 ジャンパ→0x41, ヘッダ実装規約) + ESP32 I2C 疎通 | M0 準備完了 | — | ✅ |
| EL-03 | #30 EL-03 [ファーム] CALIBRATION_MODE ビルド + ESP32 書き込み + AP 接続確認 | M0 準備完了 | — | ✅ |
| EL-04 | #31 EL-04 [電装] 実サーボを1個ずつ校正し、20駆動軸と予備を識別する | M0 準備完了 | #28, #29, #30, #13 |  |
| P-01 | #11 P-01 [運営] 購入部品の棚卸し・検品 (BOM / shopping.md D-1 と照合) | M0 準備完了 | — | ✅ |
| P-02 | #12 P-02 [運営] 印刷済みパーツの棚卸し・検品・ラベリング (旧 rev 混入チェック) | M0 準備完了 | — | ✅ |
| P-03 | #13 P-03 [測定] サーボ・ホーン実測 (STD ×14 / MG90S ×6 / ES9251II ×3) → 実測表 | M0 準備完了 | — | ✅ |
| P-04 | #14 P-04 [CAD] 実サーボ寸法を設定へ反映し、再生成・退行検査・印刷影響を記録する | M0 準備完了 | #13 |  |
| P-05 | #15 P-05 [要判断] 印刷済み品を部品別に再使用・内部加工・補強・再印刷へ分ける | M0 準備完了 | #14, #12 |  |
| P-06 | #16 P-06 [測定] 音声ユニット部品の実測 (INMP441 基板 / φ20 SPK 厚) → AUDIO_* 更新 → check_audio | M0 準備完了 | — | ✅ |
| P-07 | #17 P-07 [測定] カメラモジュール確認 (XIAO ESP32S3 Sense: センサー型番・子基板寸法・FOV) → CAM2_* 更新 → check_camera | M0 準備完了 | — | ✅ |
| P-08 | #18 P-08 [運営] イシュー運用の立ち上げ (CONTRIBUTING / テンプレ / Project ボード / 協力者招待) | M0 準備完了 | — |  |
| L-01 | #36 L-01 [組立] 脚 FL (標準版) を組む — 片脚ゲート用の 1 本目 | M1 片脚 Go/No-Go | #22, #31, #15 |  |
| L-02 | #37 L-02 [ゲート] 片脚ベンチ試験 — 1.2kg×レバー155mm (=18.6kgf·cm) 保持 (6V) / スイープ / 保持電流 | M1 片脚 Go/No-Go | #36, #28, #30 |  |
| L-11 | #77 L-11 [要判断] 股ピッチの実力を測り、低トルク歩容・軽量化・6V対応品を比較する | M1 片脚 Go/No-Go | — |  |
| PR-04 | #22 PR-04 [印刷] 片脚試験用の標準 tibia_link ×1 を先に印刷する | M1 片脚 Go/No-Go | #14, #15 | 🖨 |
| PR-05 | #23 PR-05 [印刷] 足本体と大腿カバーを別条件で試作・不足数印刷する | M1 片脚 Go/No-Go | #14 | 🖨 |
| PR-09 | #27 PR-09 [印刷] (条件付き) 骨格の再印刷 — P-05 で「再印刷」と決まった部品のみ | M1 片脚 Go/No-Go | #15 | 🖨 |
| EL-05 | #32 EL-05 [配線] 脚サーボハーネス ×12 製作 (電源 AWG20→AWG16 バス分岐 / 信号 AWG26→PCA) | M2 頭無し歩行 | — | ✅ |
| EL-07 | #34 EL-07 [ファーム] 通常版を無負荷ベンチで確認し、初期脱力・出力方向を検証する | M2 頭無し歩行 | #30 |  |
| EL-09 | #75 EL-09 [要判断] 実電源の電圧・電流・温度から継続か交換を決める | M2 頭無し歩行 | — |  |
| L-03 | #38 L-03 [組立] 脚 FR (ミラー版 `_m`) を組む | M2 頭無し歩行 | #37, #86 | ✅ |
| L-04 | #39 L-04 [組立] 脚 RL (ミラー版 `_m`) を組む | M2 頭無し歩行 | #37, #86 | ✅ |
| L-05 | #40 L-05 [組立] 脚 RR (標準版) を組む | M2 頭無し歩行 | #37, #86 | ✅ |
| L-06 | #41 L-06 [組立] 頭無し試験用シャーシ・ヨーサーボ・仮電装を組む | M2 頭無し歩行 | #28, #29, #31, #15 | 🤖 |
| L-07 | #42 L-07 [組立] 4 脚をシャーシへ取付 (ヨーホーン共締め, 方位 FR15/FL165/RL210/RR330) | M2 頭無し歩行 | #36, #38, #39, #40, #41 | 🤖 |
| L-08 | #43 L-08 [配線] 脚 12ch 本体配線 (経路・束ね・バス直結・PCA ch 割当) | M2 頭無し歩行 | #42, #32 | 🤖 |
| L-09 | #44 L-09 [試験] 通電・中立確認・トリム (サーボ未接続電圧 → 1 本 → 全数 → Web UI Trim) | M2 頭無し歩行 | #43, #34 | 🤖 |
| L-10 | #45 L-10 [ゲート] 頭無し歩行試験 — 立位→前進→旋回→停止, 転倒なし, 電流・電圧ログ | M2 頭無し歩行 | #44 |  |
| PR-11 | #86 PR-11 [印刷] 片脚合格後に残りのtibiaを標準1本・ミラー2本印刷する | M2 頭無し歩行 | #37 | 🖨 |
| A-01 | #46 A-01 [組立] 右腕チェーンをベンチで組む (肩ブラケット→上腕→前腕→固定爪) | M3 サブアセンブリ | #31, #14, #98 | ✅ |
| A-02 | #47 A-02 [組立] 左腕チェーンをベンチで組む (_L パーツ) | M3 サブアセンブリ | #31, #14, #98 | ✅ |
| A-03 | #48 A-03 [組立] 肩ヨーサーボ ×2 をシャーシへ + 両腕を吊り下げ + 配線 + ベンチ確認 (TUCK/READY/REACH/WAVE) | M3 サブアセンブリ | #46, #47, #42, #33, #34, #90, #91 | 🤖 |
| EL-06 | #33 EL-06 [配線] 腕・目サーボハーネス製作 (MG90S ×6 / ES9251II ×2, AWG26/30) | M3 サブアセンブリ | — | ✅ |
| H-01 | #50 H-01 [組立] 目ポッド ×2 (キョロキョロ) — ドット黒仕上げ / ES9251II / ホーン先付け / 中立位相 | M3 サブアセンブリ | #31, #14 | ✅ |
| H-02 | #51 H-02 [組立] カメラ目 — 子基板→camera_carrier→base→shell 接着, XIAO ファーム + WiFi 静止画疎通 | M3 サブアセンブリ | #17, #79 | ✅ |
| H-03 | #52 H-03 [組立] 音声ユニット組込 — INMP441→cradle_mic 圧入 / φ20 SPK / cradle_spk / 8 芯を Neck・Ball ボアへ | M3 サブアセンブリ | #25, #12, #89 | ✅ |
| H-04 | #53 H-04 [電装] 裸配線のI2S音声をmock・PTT・低音量再生でベンチ確認する | M3 サブアセンブリ | #34 |  |
| H-05 | #54 H-05 [組立] 改訂Mouth一式の挿入・小キー公差・配線を確認する | M3 サブアセンブリ | #52, #89 | ✅ |
| PR-01 | #19 PR-01 [印刷] キット灰意匠を不足・嵌合条件別に分離して印刷する | M3 サブアセンブリ | #12 | 🖨 |
| PR-02 | #20 PR-02 [印刷] 黒いトゥ・指・Insertを部品別の確定条件で印刷する | M3 サブアセンブリ | #12 | 🖨 |
| PR-06 | #24 PR-06 [印刷] 首・腕・目・カメラ・音声受けを個別条件で引き渡す | M3 サブアセンブリ | #14 | 🖨 |
| PR-07 | #25 PR-07 [印刷] Mouth_Cannon_Bored + Mouth_Ball_Bored (+ Neck / mic クレードルは変更時のみ) | M3 サブアセンブリ | #16, #89 | 🖨 |
| PR-10 | #79 PR-10 [印刷] 実カメラ版に合うbase・shell・carrierを1組確認する | M3 サブアセンブリ | #17, #12 | 🖨 |
| A-04 | #49 A-04 [仕上げ] 腕殻の改訂配置とGuard原型・左右対応を確認して固定する | M4 フルドレス | #48 | 🤖 |
| EL-08 | #35 EL-08 [電装] WS2812 ×12 + 74AHCT125 + DFPlayer (+microSD 音源) のベンチ配線・点灯/再生確認 | M4 フルドレス | #34 | ✅ |
| H-06 | #55 H-06 [CAD] Cabin内部の電装室・基板保持・挿入経路・配線を成立させる | M4 フルドレス | — | ✅ |
| PR-03 | #21 PR-03 [印刷] 赤ランプ大4・小4の不足分を透光試験後に用意する | M4 フルドレス | #12 | 🖨 |
| PR-08 | #26 PR-08 [印刷] 頭の収納・支持確定後にHeadTopの再使用か改訂印刷を判断する | M4 フルドレス | #12, #90, #94 | 🖨 |
| S-01 | #57 S-01 [組立] pod_neck 取付 + TailJoint (青コーン+Ball リング) 化粧スリーブ接着 | M4 フルドレス | #41, #96, #88 | 🤖 |
| S-02a | #58 S-02a [仕上げ] 脚 FL の装飾 — thigh_cap / Thigh_Guard / shin_shell (標準) / Shin_Guard / Leg_Toe ×3 | M4 フルドレス | #45, #87, #95, #97 | 🤖 |
| S-02b | #59 S-02b [仕上げ] 脚 FR の装飾 — thigh_cap / Thigh_Guard / shin_shell_m (ミラー) / Shin_Guard / Leg_Toe ×3 | M4 フルドレス | #45, #87, #95, #97 | 🤖 |
| S-02c | #60 S-02c [仕上げ] 脚 RL の装飾 — thigh_cap / Thigh_Guard / shin_shell_m (ミラー) / Shin_Guard / Leg_Toe ×3 | M4 フルドレス | #45, #87, #95, #97 | 🤖 |
| S-02d | #61 S-02d [仕上げ] 脚 RR の装飾 — thigh_cap / Thigh_Guard / shin_shell (標準) / Shin_Guard / Leg_Toe ×3 | M4 フルドレス | #45, #87, #95, #97 | 🤖 |
| S-03 | #62 S-03 [組立] 頭部組立 — Head_Bottom_Armcut / 目ポッド ×2 + カメラ目装着 / Head 装飾 / Head_Top 被せ | M4 フルドレス | #50, #51, #55, #26, #45, #90, #94, #67 | 🤖 |
| S-04 | #63 S-04 [組立] Mouth 一式を頭部ソケットへ取付 (Ball スナップ, -18° 下向きポーズ, 配線 φ7 穴→MAX98357A) | M4 フルドレス | #54, #62 | 🤖 |
| S-05 | #64 S-05 [仕上げ] Cabinの電装室・接合・目座が確定した部品を組む | M4 フルドレス | #55, #96 | ✅ |
| S-06 | #65 S-06 [組立] 採用した首とCabinの支持・締結・通線を実物で確認する | M4 フルドレス | #64, #57 | 🤖 |
| S-07 | #66 S-07 [電装] LED ×12 / DFPlayer / 74AHCT125 を本体へ組込 (直列順 0→11, 目 LED は carrier 裏) | M4 フルドレス | #35, #62, #65 | 🤖 |
| S-08 | #67 S-08 [要判断] 頭Insert・Screwの位置と受け座・挿入経路を照合する | M4 フルドレス | — |  |
| EL-10 | #76 EL-10 [ファーム] アイドル時の発熱対策 — 一定時間無指令で休止姿勢 / 段階脱力 (S-07) | M5 統合・完成 | #34 | ✅ |
| H-07 | #56 H-07 [要判断] CH_HEAD/ch12を予備・未接続として実物確認する | M5 統合・完成 | — |  |
| I-01 | #68 I-01 [測定] 全装備の実重量・支持荷重・重心を測りモデルへ反映する | M5 統合・完成 | #62, #63, #65, #66, #49, #58, #59, #60, #61 | 🤖 |
| I-02 | #69 I-02 [試験] フルドレス歩行調整 (Trim / 体高 115・歩幅 50% から / 腕 TUCK / foot_pad 滑り / 電流電圧ログ) | M5 統合・完成 | #68, #45, #78, #87, #88 | 🤖 |
| I-03 | #70 I-03 [ファーム] 音声会話の実運用 (iPhone テザリング 2.4GHz / STA 設定 / mDNS / API キー / voice_bridge) | M5 統合・完成 | #53 |  |
| I-04 | #71 I-04 [ファーム] カメラ連携 (voice_bridge --camera-url で「見て」に答える) | M5 統合・完成 | #51, #70 |  |
| I-05 | #72 I-05 [試験] 演出確認 — 目 (KYORO/FRONT/SCAN + 歩行方向バイアス) / LED / DFPlayer 起動音 | M5 統合・完成 | #66, #69 | 🤖 |
| I-06 | #73 I-06 [ドキュメント] 組立で得た現物合わせ知見を docs へ反映 (assembly / wiring / print_manifest / HANDOFF) | M5 統合・完成 | — | ✅ |
| I-07 | #74 I-07 [運営] 完成お披露目 — 写真・動画・README 更新 | M5 統合・完成 | #69, #70, #71, #72, #73 |  |
| I-08 | #78 I-08 [検証] 実購入個体の照合後に物理モデル・自己干渉・材料別接触を再評価する | M5 統合・完成 | — | ✅ |
| RV-01 | #81 RV-01 [不具合] 操作画面・低電圧停止・腕脚ガードを修正して回帰検証する |  | — | ✅ |
| RV-02 | #82 RV-02 [検証] 現物3MFの形状・数量・材質と再生成時の保持を検査する |  | — | ✅ |
| RV-03 | #83 RV-03 [不具合] 幾何・歩容検査のNGと計算失敗を終了コードへ反映する |  | — |  |
| RV-04 | #84 RV-04 [不具合] Issue同期で進捗を保持し、重複と依存関係を検証する |  | — | ✅ |
| RV-05 | #85 RV-05 [ゲート] 修正後の全検証と未確認の実機条件を記録する |  | #81, #82, #83, #84, #78, #87, #88, #89, #90, #91, #92, #93, #94, #95, #96, #97, #98, #55 |  |
| RV-06 | #87 RV-06 [機構不具合] トゥと硬い足本体の先行接地を解消して足裏支持を成立させる |  | — |  |
| RV-07 | #88 RV-07 [試験] 実際の壁数・充填率による脚とポッド支持の強度を確かめる |  | — |  |
| RV-08 | #89 RV-08 [機構不具合] 修正済みMouth挿入路に残る小キー公差・実保持を確定する |  | — | ✅ |
| RV-09 | #90 RV-09 [機構不具合] 頭部内の実サーボケースとポッド梁の干渉を解消する |  | — | ✅ |
| RV-10 | #91 RV-10 [機構不具合] 肩と前脚のケース干渉・腕Guardの原型対応を解消する |  | — | ✅ |
| RV-11 | #92 RV-11 [電装] 部品の実型番・電源収支・停止回路・測定手順を整合させる |  | — | ✅ |
| RV-12 | #93 RV-12 [検証] 表示用モデルと全ファイルの検査記録を実設計に合わせる |  | — | ✅ |
| RV-13 | #94 RV-13 [機構不具合] 頭の7固定穴から外殻へ届く支持柱・受け座を設計する |  | #90 |  |
| RV-14 | #95 RV-14 [機構不具合] シャーシと大腿カバーの実交差を解消する |  | #90 |  |
| RV-15 | #96 RV-15 [機構不具合] 首・Cabin・装飾を全長で組み合わせ、支持と挿入を成立させる |  | — | ✅ |
| RV-16 | #97 RV-16 [機構不具合] 大腿・脛ガードの受け座と実際に入る組立経路を作る |  | — | ✅ |
| RV-17 | #98 RV-17 [機構不具合] 固定爪・指・指飾りの嵌合公差と接着座を検証する |  | — | ✅ |
<!-- END GENERATED -->

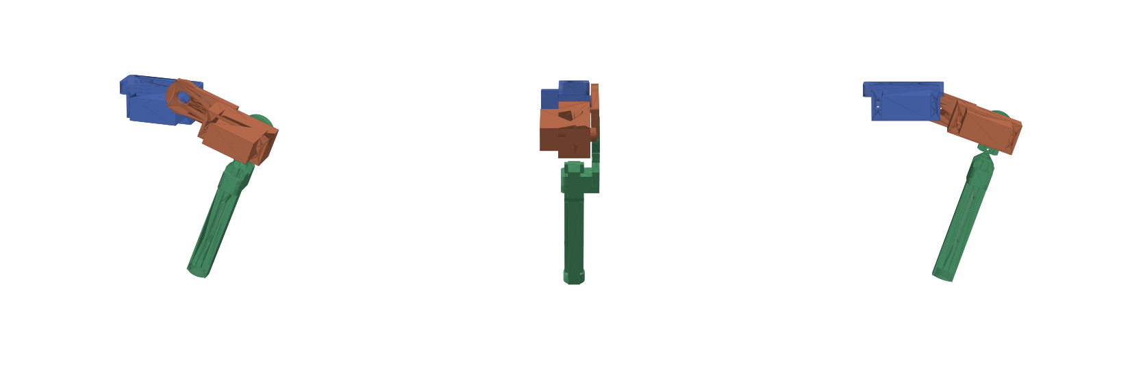
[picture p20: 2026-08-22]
docs/preview_leg_assembly.png

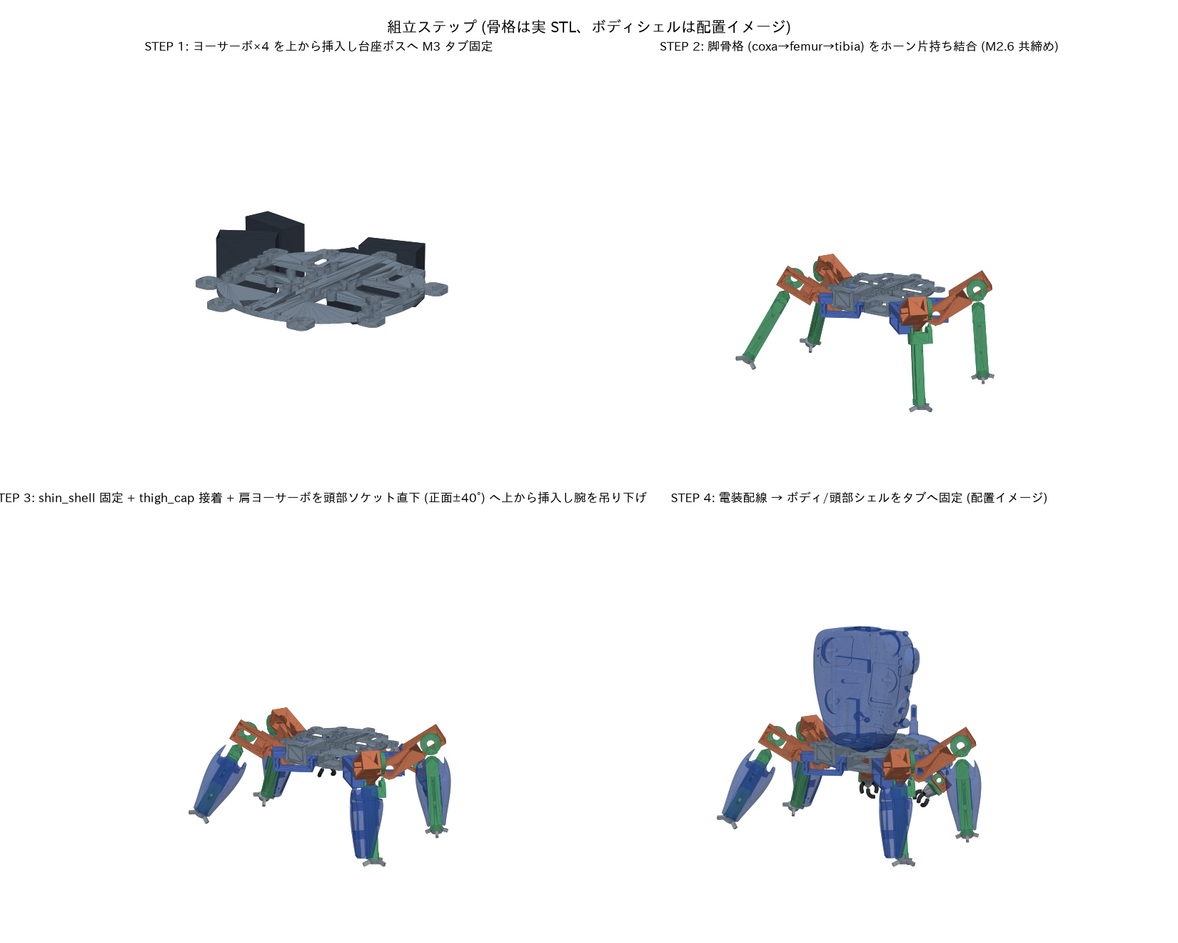
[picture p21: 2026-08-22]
docs/vis_assembly_steps.png

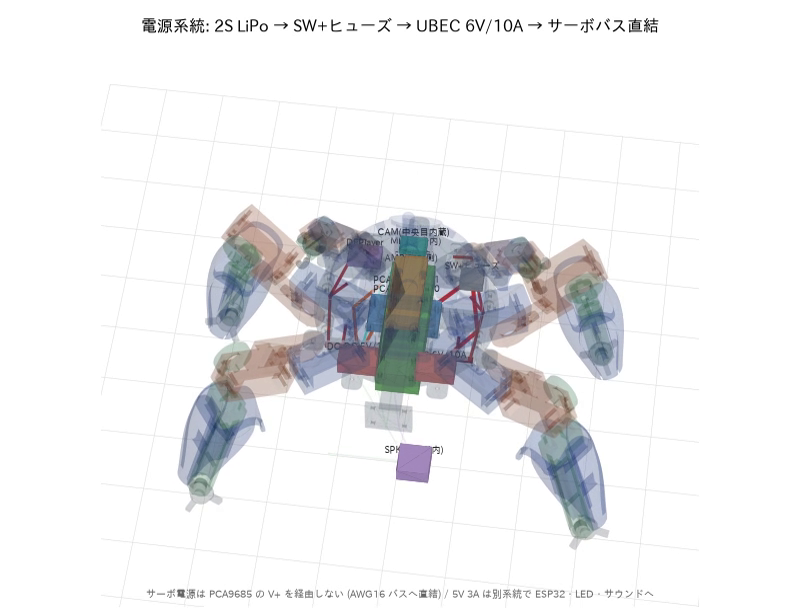
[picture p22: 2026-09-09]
docs/audits/20260905-round2/media-review/vis_wiring-5.png

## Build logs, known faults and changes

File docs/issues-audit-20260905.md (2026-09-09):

# 107課題の見直し — 2026-09-05

監査で確認した実施済みの範囲と、現物・設計・製作の未完了を107件すべてで書き分けた。旧本文へ注意書きを追加するだけでは古い手順が残るため、各本文を現在地・次の具体作業・完了証拠・購入/印刷との対応へ置き換えた。

実購入ケースと設計基準ケースは未照合。外部記録の現物確認履歴は数量確認として扱い、実物寸法・性能・印刷済み個数の証明にはしない。外部記録、住所、価格、無関係な外部記録は公開資料へ含めない。

既存ClosedはRV-01/02/03/04/12（#81/#82/#83/#84/#93）の5件を維持する。他91件はOPEN。以下のProject状態は見直し案であり、GitHub反映済みを意味しない。同期後の実状態は別の照合記録で確認する。

**反映確認追記（2026-09-05 18:32 JST）:** 以下の案を全107件へ反映し、本文・タイトル・依存・Projectの状態/分類を読戻し確認した。既存担当・11コメント・Closed5件を保持。照合の詳細は[GitHub反映記録](audits/20260905-parts-issues/publication.json)を参照。

## 同期と保存の境界

- 正本文は `tools/issues/plan.py` と `audit_plan_data.py`。107キーを保ち、新規課題を重複作成しない。
- 文書リンクは `codex/print-first-20260905` に統一。監査コミット `0de71547c1af59abc6bcc3484b03b12e9430df2b` の46固定リンクは変更しない。
- 既存の担当・コメントは保持する。実機の組立・書込・印刷・追加購入をこの文書更新によって完了扱いにしない。
- 新発見の腕Guard原型/左右対応はRV-10・PR-01・A-04で追跡する。Closed RV-12の過去の検証範囲を広げず、修正後に表示/URDF回帰を追加する。

## 直列と並行の扱い

完了待ちの依存は173本から156本へ変更（追加23・削除40、30課題）。107キーの参照と循環なしを機械検査した。

1. 棚卸し・各型式の測定・電源/PCA準備・裸音声・無負荷ファームは独立して進める。型番/許容電圧未確認でのサーボ中立化はP-03で止める。
2. FL標準tibia1本のPR-04→L-01→L-02→PR-11→残3脚を維持。材料強度と足の床支持はサーボ保持試験の合格とは別に確認する。
3. 混載プレートの全品完了を受入条件にしない。受入側が自分の部品名/数量/版/寸法/保持を確認してコメントし、印刷台帳の該当行を更新する。設計未確定部品の印刷を解放する意味ではない。
4. 頭無しL-06は脱着できる仮電装。本体の最終腕取付は実脚L-07とRV-09/RV-10のケース修正後。頭収納RV-09→頭支持RV-13・脚カバーRV-14は直列のまま。
5. 首/CabinのRV-15とH-06、脚ガードRV-16、手RV-17は境界寸法を共有して並行調査できる。共通生成ファイルの編集とSTL→頭加工→URDF→最終検証は直列にする。
6. プリンタ1台は予約で排他。色別プレート間に任意の完了待ちを追加しない。本体上の装飾4脚、腕殻、演出は本体を占有する作業として同時に行わない。部品単体の下処理は別に先行できる。

## 変更した依存の理由

| 課題 | 追加 | 削除 | 理由 |
|---|---|---|---|
| [P-05 #15](https://github.com/hapx2yuki/Tachikoma/issues/15) | P-02 | — | 実測差分だけでなく、現物の使用版/印刷設定の照合を再使用判断の前提に追加。 |
| [PR-01 #19](https://github.com/hapx2yuki/Tachikoma/issues/19) | P-02 | — | 灰一式の即印刷を撤回。まず実在庫と版を確認し、部品ごとの未解決条件で分離。 |
| [PR-02 #20](https://github.com/hapx2yuki/Tachikoma/issues/20) | P-02 | — | 黒一式の即印刷を撤回。150%toeと指/Insertの実在庫・用途を確認して分離。 |
| [PR-03 #21](https://github.com/hapx2yuki/Tachikoma/issues/21) | P-02 | — | 赤ランプも現物不足を確定して重複印刷を避ける。独立した透光見本は先行可能。 |
| [PR-06 #24](https://github.com/hapx2yuki/Tachikoma/issues/24) | — | P-07、RV-09、RV-10、RV-15 | Restの首/眼/カメラ待ちを全品へ波及させない。各部品の実測/設計合格を受入側で確認する。 |
| [PR-08 #26](https://github.com/hapx2yuki/Tachikoma/issues/26) | RV-13 | — | ケース収納だけでは頭が固定できないため、頭支持RV-13の確定を追加。 |
| [PR-10 #79](https://github.com/hapx2yuki/Tachikoma/issues/79) | P-02、P-07 | — | 旧カメラbaseを無条件再印刷せず、現センサー版と既印刷品を確認する。 |
| [EL-04 #31](https://github.com/hapx2yuki/Tachikoma/issues/31) | P-03 | — | 許容電圧/型番の未同定サーボへ一律6Vを投入しないため実測P-03を追加。 |
| [EL-07 #34](https://github.com/hapx2yuki/Tachikoma/issues/34) | — | P-04 | 無負荷の通常ファーム検証は全機CAD更新を待たない。本体の荷重試験はL-09に残す。 |
| [L-01 #36](https://github.com/hapx2yuki/Tachikoma/issues/36) | — | PR-05 | 足1個の検品は必要だが、大腿カバー4個を含むPR-05全体の完了はFLベンチに不要。 |
| [A-01 #46](https://github.com/hapx2yuki/Tachikoma/issues/46) | P-04 | PR-01、PR-02、PR-06、RV-10 | 右腕の個別部品受入れへ変更。混載印刷/本体ケース問題を単体腕へ広げず、実測をCADに反映するP-04を直接追加し、固定手RV-17を維持。 |
| [A-02 #47](https://github.com/hapx2yuki/Tachikoma/issues/47) | P-04 | PR-01、PR-02、PR-06、RV-10 | 左腕も個別部品受入れへ変更。実測のCAD反映P-04を直接追加し、先行_L在庫の確認と固定手RV-17を完了条件に残す。 |
| [A-03 #48](https://github.com/hapx2yuki/Tachikoma/issues/48) | L-07、RV-09、RV-10 | L-06 | 本体へ吊る時は実脚が必要。L-06をL-07へ進め、実干渉のある軸配置RV-09/肩ケースRV-10を追加。 |
| [H-01 #50](https://github.com/hapx2yuki/Tachikoma/issues/50) | P-04 | PR-06 | 眼の受けだけを引渡し、首/腕/カメラ全体待ちを解除。実測を受けへ反映するP-04を直接追加し、頭への接着はS-03で制御。 |
| [H-02 #51](https://github.com/hapx2yuki/Tachikoma/issues/51) | — | PR-06 | カメラ1組に無関係なRest全体の完了を不要化。現センサーとカメラ部品の確認は維持。 |
| [H-03 #52](https://github.com/hapx2yuki/Tachikoma/issues/52) | — | PR-06 | 音声受け1個の検品へ分離し、Restの首/眼待ちを解除。音声実測/改訂口/旧品照合は維持。 |
| [H-04 #53](https://github.com/hapx2yuki/Tachikoma/issues/53) | — | H-03 | I2S裸ベンチを砲身組込の完了待ちから分離。組込後音響はH-03/S-04で再確認。 |
| [H-05 #54](https://github.com/hapx2yuki/Tachikoma/issues/54) | — | PR-01 | 必要なCap/Key/Pegだけを個別受入れし、灰一式印刷の完了待ちを解除。小キー公差RV-08は維持。 |
| [S-01 #57](https://github.com/hapx2yuki/Tachikoma/issues/57) | — | PR-01、PR-06 | 採用した首部品の受入れへ変更。腕/眼/灰小物全体待ちは不要、首全体成立/強度は維持。 |
| [S-02a #58](https://github.com/hapx2yuki/Tachikoma/issues/58) | — | PR-01、PR-02、PR-05 | FLに必要な部品行を個別受入れ。灰/黒/大腿混載プレート完了は不要、歩行/支持/カバー/ガードの設計条件は維持。 |
| [S-02b #59](https://github.com/hapx2yuki/Tachikoma/issues/59) | — | PR-01、PR-02、PR-05 | FR鏡像の個別部品受入れへ変更。歩行/支持/カバー/ガードの成立を維持。 |
| [S-02c #60](https://github.com/hapx2yuki/Tachikoma/issues/60) | — | PR-01、PR-02、PR-05 | RL鏡像の個別部品受入れへ変更。歩行/支持/カバー/ガードの成立を維持。 |
| [S-02d #61](https://github.com/hapx2yuki/Tachikoma/issues/61) | — | PR-01、PR-02、PR-05 | RR標準の個別部品受入れへ変更。歩行/支持/カバー/ガードの成立を維持。 |
| [S-03 #62](https://github.com/hapx2yuki/Tachikoma/issues/62) | S-08 | PR-01、PR-02 | 頭に必要な装飾だけを受入れ、灰/黒一式を待たない。実測ラベル付きInsert/Screwにも交差があるためS-08の受け座/挿入成立を追加し、眼/カメラ/電装/収納/支持を維持。 |
| [S-05 #64](https://github.com/hapx2yuki/Tachikoma/issues/64) | — | PR-01、PR-02、PR-03 | Cabin用の不足意匠を個別受入れし、手や脚を含む色別一式待ちを解除。電装室/首全体の成立は必須。 |
| [I-01 #68](https://github.com/hapx2yuki/Tachikoma/issues/68) | S-04、S-07 | — | 完成重量から漏れていたMouth取付とLED/DFPlayer/配線を追加。 |
| [I-02 #69](https://github.com/hapx2yuki/Tachikoma/issues/69) | I-08、L-10 | — | 頭無し歩行と対象個体反映後の物理検証を明示的な前提に追加。足支持/印刷強度は維持。 |
| [I-03 #70](https://github.com/hapx2yuki/Tachikoma/issues/70) | — | S-04 | 裸音声の実ネットワーク/API往復は頭/Mouth組立を待たない。装着後試験はS-04へ残す。 |
| [I-07 #74](https://github.com/hapx2yuki/Tachikoma/issues/74) | I-04、I-06 | — | カメラ連携と実物知見の文書反映も完成紹介の前提として明示。 |
| [RV-05 #85](https://github.com/hapx2yuki/Tachikoma/issues/85) | RV-06、RV-07 | — | 全体判定から欠けていた足支持RV-06と印刷強度RV-07を追加。 |

## 全107課題の個別確認

次の表の「次作業」は着手可能な範囲と採用/完了の条件を含む。Blockedでも、依存を前提にしない採寸・候補比較・資料整理は本文の条件内で先行できる。

### 全体

| 課題 | 状態案・進捗 | 現在地／未完理由 | 次の具体作業／完了証拠 | 完了待ち | 購入・印刷 |
|---|---|---|---|---|---|
| [E1 #3](https://github.com/hapx2yuki/Tachikoma/issues/3) | OPEN / Todo<br>棚卸し・実測待ち | 2026-09-05に外部記録から脚14・MG90S11・ES9251II3などを照合した。現物型番・寸法・印刷使用版の実測表は未提出で、現物確認を準備完了の根拠にしない。 | P-01/P-02で現物を一覧化し、P-03/P-06/P-07の各実測を並行して進める。P-04は実測反映と影響整理、P-05は部品ごとの再使用判断を行う。<br>証拠: 子課題の実測・版照合・再使用判断が揃い、未解決設計を隠さず下流条件へ渡した記録。 | なし | [AP-001](additional-purchases.md#ap-001) / [AP-002](additional-purchases.md#ap-002) / [AP-003](additional-purchases.md#ap-003) / [AP-004](additional-purchases.md#ap-004) / [AP-094](additional-purchases.md#ap-094)；[既存3MFと印刷手順](additional-printing.md#plates) / [脚骨格・足](additional-printing.md#leg-frame) |
| [E2 #4](https://github.com/hapx2yuki/Tachikoma/issues/4) | OPEN / Todo<br>個別印刷条件の整理済み | 既存3MF27個中9個は現行STLと不一致。未変更の意匠にも嵌合未解決品があり、旧プレート順の一括印刷はできない。 | 追加印刷一覧の部品行で欠品・版・条件を照合する。プリンタ1台を予約し、必要な標準1個の試験から残数へ進む。PR-04→L-02→PR-11を優先し、設計待ちを他部品へ広げない。<br>証拠: 必要部品ごとの印刷/再使用/不要を記録し、使用STLと3MFのSHA・材質・設定・個数・写真を保存。 | なし | [AP-120](additional-purchases.md#ap-120) / [AP-125](additional-purchases.md#ap-125) / [AP-126](additional-purchases.md#ap-126) / [AP-128](additional-purchases.md#ap-128)；[既存3MFと印刷手順](additional-printing.md#plates) / [脚骨格・足](additional-printing.md#leg-frame) / [腕](additional-printing.md#arm) / [頭・カメラ・音声](additional-printing.md#head-camera-audio) / [首・Cabin・意匠](additional-printing.md#cabin-decor) / [未採用候補](additional-printing.md#candidates) |
| [E3 #5](https://github.com/hapx2yuki/Tachikoma/issues/5) | OPEN / Todo<br>ソフト検証済み・電装実測待ち | 通常/校正ビルドとホスト故障注入は合格。購入電源の型番・20軸の電流・独立停止の実効性は未測定。 | 電源単体、PCA疎通、無負荷ファーム、線材準備を並行する。通電は型番の許容電圧と外部停止を確認し、1軸から増やす。<br>証拠: EL各課題の実機ログ、電源収支・配線・独立停止・個体校正表が揃う。 | なし | [AP-004](additional-purchases.md#ap-004) / [AP-007](additional-purchases.md#ap-007) / [AP-009](additional-purchases.md#ap-009) / [AP-028](additional-purchases.md#ap-028) / [AP-030](additional-purchases.md#ap-030) / [AP-031](additional-purchases.md#ap-031)；[頭・カメラ・音声](additional-printing.md#head-camera-audio) / [首・Cabin・意匠](additional-printing.md#cabin-decor) |
| [E4 #6](https://github.com/hapx2yuki/Tachikoma/issues/6) | OPEN / Todo<br>片脚実機ゲート待ち | 現サーボの実力と脚印刷強度は未確認。coxa局所干渉は修正したが、足支持と全装備のケース/カバー干渉が残る。 | FLの標準1本を組みL-02で段階荷重する。合格後に残り3脚を並行組立し、本体はL-06→L-07→L-08→L-09→L-10の順とする。頭無し仮配置と最終配置を区別する。<br>証拠: 片脚保持・頭無し歩行の実測動画と条件が揃う。全装備の不成立を頭無し合格で免除しない。 | なし | [AP-004](additional-purchases.md#ap-004) / [AP-008](additional-purchases.md#ap-008) / [AP-020](additional-purchases.md#ap-020) / [AP-125](additional-purchases.md#ap-125)；[脚骨格・足](additional-printing.md#leg-frame) |
| [E5 #7](https://github.com/hapx2yuki/Tachikoma/issues/7) | OPEN / Todo<br>局所修正済み・組立未確認 | 肩/上腕/前腕の内部逃げと肘殻配置は修正済み。肩ケース対前脚ケース、固定手、腕Guardの左右原型対応が残る。 | 左右の単体骨格は個別部品の検査後に並行する。本体への吊下げはRV-09/RV-10、固定爪の接着はRV-17、Guardは現物と表示原型の対応確定後に行う。<br>証拠: 左右の単体・本体干渉・固定手・外装の証拠を分けて完了。 | なし | [AP-021](additional-purchases.md#ap-021) / [AP-025](additional-purchases.md#ap-025) / [AP-073](additional-purchases.md#ap-073) / [AP-083](additional-purchases.md#ap-083)；[腕](additional-printing.md#arm) |
| [E6 #8](https://github.com/hapx2yuki/Tachikoma/issues/8) | OPEN / Todo<br>単体試験・収納設計待ち | 音声挿入路は修正した。目の固定ケース、カメラ版/FPC、頭内収納、Cabin電装室は未確定。CH_HEADの駆動物は無い。 | 目・カメラ・裸音声は別ベンチで試す。P-03/P-06/P-07の実測を各保持部へ反映し、頭内はRV-09、電装室はH-06と接合面を共有する。<br>証拠: 各単体の実動作・挿入/保持と必要配線が揃い、本体取付条件を明記。 | なし | [AP-022](additional-purchases.md#ap-022) / [AP-054](additional-purchases.md#ap-054) / [AP-055](additional-purchases.md#ap-055) / [AP-056](additional-purchases.md#ap-056) / [AP-059](additional-purchases.md#ap-059)；[頭・カメラ・音声](additional-printing.md#head-camera-audio) / [首・Cabin・意匠](additional-printing.md#cabin-decor) |
| [E7 #9](https://github.com/hapx2yuki/Tachikoma/issues/9) | OPEN / Todo<br>機構修正待ち | 頭支持、首/Cabin、ガード受け座が未成立。既印刷外装をそのまま接着する段階ではない。 | RV-13/14/15/16で支持・公差・挿入経路を確定する。無加工の部品照合と仕上げ見本は並行可能。共通シャーシ/Cabinの編集・本体取付は予約して直列にする。<br>証拠: 全装備の支持・配線・取り外し・干渉の実機証拠と、旧品の再使用判断を残す。 | なし | [AP-006](additional-purchases.md#ap-006) / [AP-071](additional-purchases.md#ap-071) / [AP-077](additional-purchases.md#ap-077) / [AP-083](additional-purchases.md#ap-083) / [AP-087](additional-purchases.md#ap-087)；[頭・カメラ・音声](additional-printing.md#head-camera-audio) / [首・Cabin・意匠](additional-printing.md#cabin-decor) / [未採用候補](additional-printing.md#candidates) |
| [E8 #10](https://github.com/hapx2yuki/Tachikoma/issues/10) | OPEN / Todo<br>実機統合待ち | 89条件の物理計算は条件付きで、機体の実歩行・会話・撮影を確認していない。 | I-08で実対象個体へモデルを更新し、実機は重量/重心→全装備歩行へ進む。会話・カメラの裸ベンチ連携とI-06の記録更新は先行できる。<br>証拠: 実機の歩行・会話・撮影・演出と使用条件、完成写真・再現手順が揃う。 | なし | [AP-004](additional-purchases.md#ap-004) / [AP-010](additional-purchases.md#ap-010) / [AP-011](additional-purchases.md#ap-011) / [AP-012](additional-purchases.md#ap-012)；[未採用候補](additional-printing.md#candidates) / [既存3MFと印刷手順](additional-printing.md#plates) |
| [E9 #80](https://github.com/hapx2yuki/Tachikoma/issues/80) | OPEN / In Progress<br>監査実施済み・是正継続 | 開始時515ファイル、生成3工程、23検査、89動的条件を記録。ソフト/検査器の5課題を完了したが、機構・電装の実物条件は残る。 | 閉じたRV-01/02/03/04/12を維持し、各未解決RVとP-02/P-03の現物照合を進める。最終再生成は共通CAD変更をまとめて直列実施する。<br>証拠: RV-05で未解決設計・実測ゲートの判定を更新し、監査実施と機体完成を区別する。 | なし | [AP-004](additional-purchases.md#ap-004) / [AP-007](additional-purchases.md#ap-007) / [AP-094](additional-purchases.md#ap-094)；[未採用候補](additional-printing.md#candidates) / [既存3MFと印刷手順](additional-printing.md#plates) |

### 準備

| 課題 | 状態案・進捗 | 現在地／未完理由 | 次の具体作業／完了証拠 | 完了待ち | 購入・印刷 |
|---|---|---|---|---|---|
| [P-01 #11](https://github.com/hapx2yuki/Tachikoma/issues/11) | OPEN / Ready<br>現物・実行証拠待ち | 2026-09-05の外部記録で記録上の脚候補14個、MG90S11、ES9251II3を確認。M2.5スタンドオフ320セット、M2/M2.5ねじ430セット(M2.5×6含む)、SPL82×6は外部記録あり。PCA2枚は現物未確認・現物未確認。 | 追加購入一覧を現物ラベル・数量・端子と照合する。M2.5×16のセット内包有無、φ2.2刃/DC電流計/microSDの手持ちを確認する。現物未確認品を欠品と推測して重複発注せず、無関係な外部記録/住所を公開しない。<br>証拠: 有無/未確認/不足/仕様違いの表とラベル写真。現物確認を使用可能在庫へ読み替えず、必要な行だけ手配対象にする。 | なし | [AP-001](additional-purchases.md#ap-001) / [AP-002](additional-purchases.md#ap-002) / [AP-003](additional-purchases.md#ap-003) / [AP-004](additional-purchases.md#ap-004) / [AP-005](additional-purchases.md#ap-005) / [AP-006](additional-purchases.md#ap-006) / [AP-007](additional-purchases.md#ap-007)；[既存3MFと印刷手順](additional-printing.md#plates) |
| [P-02 #12](https://github.com/hapx2yuki/Tachikoma/issues/12) | OPEN / Ready<br>現物・実行証拠待ち | 過去の印刷済み申告は現物未照合。形状変更はSTL10ファイル・12個分、配置のみ2ファイル。現設計139個＋予備2個は追加数ではない。Restは8種9個で肩/上腕が無く、Blue1は標準shin1、Blue2はHeadBottom1、TPUは1個のみ収録。9個の3MF不一致と腕7部品の2壁/15%も検出した。 | 追加印刷一覧の部品別に元3MF・使用日・材料・壁数・数量を写真付きで照合する。標準/鏡像をラベル付けし、旧品は保存してP-05へ渡す。<br>証拠: 部品ごとの再使用/加工検討/再印刷/未確認の表。elbowは形状同一、toeは既存150%を再拡大しないと記録。 | なし | [AP-094](additional-purchases.md#ap-094) / [AP-116](additional-purchases.md#ap-116) / [AP-128](additional-purchases.md#ap-128)；[既存3MFと印刷手順](additional-printing.md#plates) / [脚骨格・足](additional-printing.md#leg-frame) / [腕](additional-printing.md#arm) / [頭・カメラ・音声](additional-printing.md#head-camera-audio) / [首・Cabin・意匠](additional-printing.md#cabin-decor) |
| [P-03 #13](https://github.com/hapx2yuki/Tachikoma/issues/13) | OPEN / Ready<br>現物・実行証拠待ち | 外部記録は記録上の脚候補14個、MG90S11、ES9251II3。設計基準DS3218等との現物一致、180/270度、軸/タブ高さ、6V適合は未確認。記録上の数量を寸法確認済みと読み替えない。 | STD/MG90S/目サーボを型式ごと3個体以上、0.05mmノギスで測る。ケースL/W、ギヤ部込みタブ上/下・厚、穴スパン/ピッチ/径、軸偏心/歯数、中心ビス、ホーンのハブ径/厚/腕穴距離/腕厚、線出口を記録する。型番/許容電圧を通電前に照合する。<br>証拠: config.pyキー対応の実測表とノギス/ラベル写真。駆動脚12/腕6/目2と対象脚14/MG90S11/目3を区別し、残数の健全性もP-04/EL-04へ渡す。 | なし | [AP-020](additional-purchases.md#ap-020) / [AP-021](additional-purchases.md#ap-021) / [AP-022](additional-purchases.md#ap-022) / [AP-024](additional-purchases.md#ap-024) / [AP-025](additional-purchases.md#ap-025) / [AP-026](additional-purchases.md#ap-026) / [AP-094](additional-purchases.md#ap-094)；[脚骨格・足](additional-printing.md#leg-frame) / [腕](additional-printing.md#arm) / [頭・カメラ・音声](additional-printing.md#head-camera-audio) |
| [P-04 #14](https://github.com/hapx2yuki/Tachikoma/issues/14) | OPEN / Blocked<br>現物・実行証拠待ち | 公称値による生成・検査は済んだが、実購入寸法への更新は未実施。全機の既知NGを消すことと実測反映は別作業。 | P-03の実測で必要な設定だけ更新し、変更前SHAを保存してSTL→頭加工→URDFを再生成する。全検査結果を保存し新規退行を直す。3MFは別出力へ必要分だけ作る。<br>証拠: 実測差分、変更STL一覧、影響する旧印刷品、全検査の結果と残件の対応表。無関係なRVの完了まで実測表の引渡しを止めない。 | P-03 | [AP-094](additional-purchases.md#ap-094)；[既存3MFと印刷手順](additional-printing.md#plates) / [脚骨格・足](additional-printing.md#leg-frame) / [腕](additional-printing.md#arm) / [頭・カメラ・音声](additional-printing.md#head-camera-audio) |
| [P-05 #15](https://github.com/hapx2yuki/Tachikoma/issues/15) | OPEN / Blocked<br>現物・実行証拠待ち | coxaは穴径だけでなく約5717mm³/個の内部除去、chassisは補強材追加、HeadBottomは材料復元がある。ドリルだけで全て再使用可という旧案は撤回。 | P-02/P-04を照合し、各部品の工具経路・残肉・新しい支持面を比較する。elbow2個は取付位置だけ直し、形状変更10ファイルは加工/補強/再印刷を部品別に判断する。<br>証拠: 対象と必要個数、再使用根拠、加工図または再印刷版、設計待ち理由を記録。未採用候補を一式の確定部品にしない。 | P-04、P-02 | [AP-003](additional-purchases.md#ap-003) / [AP-093](additional-purchases.md#ap-093) / [AP-100](additional-purchases.md#ap-100) / [AP-101](additional-purchases.md#ap-101) / [AP-106](additional-purchases.md#ap-106)；[脚骨格・足](additional-printing.md#leg-frame) / [腕](additional-printing.md#arm) / [頭・カメラ・音声](additional-printing.md#head-camera-audio) / [既存3MFと印刷手順](additional-printing.md#plates) |
| [P-06 #16](https://github.com/hapx2yuki/Tachikoma/issues/16) | OPEN / Ready<br>現物・実行証拠待ち | マイク挿入路とNeck/Cap座は修正済み。INMP441実装厚、φ20スピーカー厚/端子、接着公差と音響は未測定。 | INMP441の外形/厚/音孔/ピン向きとSPK径/厚/端子を測りAUDIO_*と照合する。変更があれば音声部だけ再生成しcheck_audio/check_audio_assembly/check_mouth_chassisへ通す。<br>証拠: 実測表、音声部のSHA差分、旧mic受け/Neckの再使用判断をPR-07/H-03へ渡す。 | なし | [AP-054](additional-purchases.md#ap-054) / [AP-055](additional-purchases.md#ap-055) / [AP-056](additional-purchases.md#ap-056) / [AP-057](additional-purchases.md#ap-057) / [AP-058](additional-purchases.md#ap-058) / [AP-094](additional-purchases.md#ap-094)；[頭・カメラ・音声](additional-printing.md#head-camera-audio) |
| [P-07 #17](https://github.com/hapx2yuki/Tachikoma/issues/17) | OPEN / Ready<br>現物・実行証拠待ち | 基準形状はOV2640、公開資料にはOV3660の102度/85度・EFL1.63mmがある。手元センサーの版とFPCは未同定。 | 子基板/レンズ/FPCの実物型番と寸法・画角を確認し、XIAO本体/USBも計測する。OV3660候補は原型と混ぜず全視野・取り外し・接続をH-02と確認する。<br>証拠: 現品写真・寸法/FOVの根拠・採用カメラ設定・影響するshell/base/carrierの表。基板単体撮影の実施有無を区別。 | なし | [AP-017](additional-purchases.md#ap-017) / [AP-059](additional-purchases.md#ap-059) / [AP-060](additional-purchases.md#ap-060) / [AP-064](additional-purchases.md#ap-064) / [AP-094](additional-purchases.md#ap-094)；[頭・カメラ・音声](additional-printing.md#head-camera-audio) / [未採用候補](additional-printing.md#candidates) |
| [P-08 #18](https://github.com/hapx2yuki/Tachikoma/issues/18) | OPEN / Ready<br>運用整備済み・参加確認待ち | 107課題とProjectが存在し、監査修正5課題のみClosed。旧72件/全Readyという案内は現状を表さない。 | 今回の#3〜#109の107件の本文/依存を同期し、Closed5件と既存担当・コメントを保持する。Ready/Blockedの理由を公開し、協力者の参加権限/自動進捗設定は本人の確認を記録する。<br>証拠: 107キーの重複なし照合、依存循環なし、Project URLと参加/権限の確認。招待未実施を完了扱いにしない。 | なし | [購入一覧](additional-purchases.md)；[既存3MFと印刷手順](additional-printing.md#plates) |

### 印刷

| 課題 | 状態案・進捗 | 現在地／未完理由 | 次の具体作業／完了証拠 | 完了待ち | 購入・印刷 |
|---|---|---|---|---|---|
| [PR-01 #19](https://github.com/hapx2yuki/Tachikoma/issues/19) | OPEN / Blocked<br>現物・実行証拠待ち | Gray_2にはMouth_Key、TailJoint、Shin_Guard、固定手、腕Guardが混在し、全36個を今すぐ印刷する条件はない。腕Guardは原型左右の対応にも疑義がある。 | P-02で不足を確認し、既知交差と無関係な意匠だけ別名プレートへ分離して1個試す。MouthはRV-08、首/CabinはRV-15、ガードはRV-16、手はRV-17、腕GuardはRV-10へ対応を残す。保存3MFの爪/指先は同形複製なので、現モデルの左右鏡像に実物が適合するか確認する。<br>証拠: 各オブジェクトの印刷/再使用/保留と理由、150%倍率、灰材割当、SHA・数量・写真。保留品を印刷済みにしない。 | P-02 | [AP-121](additional-purchases.md#ap-121) / [AP-129](additional-purchases.md#ap-129) / [AP-083](additional-purchases.md#ap-083) / [AP-106](additional-purchases.md#ap-106)；[腕](additional-printing.md#arm) / [首・Cabin・意匠](additional-printing.md#cabin-decor) / [既存3MFと印刷手順](additional-printing.md#plates) |
| [PR-02 #20](https://github.com/hapx2yuki/Tachikoma/issues/20) | OPEN / Blocked<br>現物・実行証拠待ち | Black_1のtoe12個は150%が正。指6個・Cabin Insert・Head Insertにも座/位置未確定があり一括印刷不可。 | 足はRV-06、指はRV-17、CabinはRV-15、Head InsertはS-08の条件で行を分ける。保存3MFの指は鏡像指定なしの同形複製で、現モデルの左右鏡像へ適合するかもRV-17と確認する。未変更で用途が確定した不足品だけ1個試し、スロット1から実PLA黒へ割当を変更する。<br>証拠: 150%と配置を確認した部品別数量/写真、未確定品の保留先、旧150%toeの再使用可否。 | P-02 | [AP-122](additional-purchases.md#ap-122) / [AP-106](additional-purchases.md#ap-106)；[脚骨格・足](additional-printing.md#leg-frame) / [腕](additional-printing.md#arm) / [首・Cabin・意匠](additional-printing.md#cabin-decor) / [既存3MFと印刷手順](additional-printing.md#plates) |
| [PR-03 #21](https://github.com/hapx2yuki/Tachikoma/issues/21) | OPEN / Blocked<br>現物・実行証拠待ち | 赤ランプ大4/小4は意匠原型を維持。大の右後側はCabinBackと交差しRV-15で追跡中。手元在庫と赤フィラメント残量、LED透過の実測は未確認。 | 小4個の不足分はP-02後に単品仮合わせ、大4個の不足分はRV-15で該当座を確認してから試す。各1個で透光・寸法を確認し、PLA赤または白+赤塗装を比較して残数へ進む。実スプール割当を保存する。<br>証拠: 必要8個の充足表、使用材/数量/写真とEL-08/S-05へ渡す透光結果。 | P-02 | [AP-123](additional-purchases.md#ap-123) / [AP-124](additional-purchases.md#ap-124)；[首・Cabin・意匠](additional-printing.md#cabin-decor) / [既存3MFと印刷手順](additional-printing.md#plates) |
| [PR-04 #22](https://github.com/hapx2yuki/Tachikoma/issues/22) | OPEN / Blocked<br>現物・実行証拠待ち | FL標準tibia1本が先行対象。旧4本3MFはそのまま送信せず、4壁/40%の公称強度は実印刷強度とは区別する。 | P-04/P-05後、現行STLを別名3MFに標準1本だけ配置する。向き・材・壁・充填を記録してL-01へ渡し、残り3本はL-02後のPR-11とする。<br>証拠: 標準1本のSHA/設定/写真・実重量と主要嵌合。L-02前に残3本を量産しない。 | P-04、P-05 | [AP-125](additional-purchases.md#ap-125) / [AP-128](additional-purchases.md#ap-128)；[脚骨格・足](additional-printing.md#leg-frame) / [既存3MFと印刷手順](additional-printing.md#plates) |
| [PR-05 #23](https://github.com/hapx2yuki/Tachikoma/issues/23) | OPEN / Blocked<br>現物・実行証拠待ち | 足本体4個とthigh_cap4個は同一プレートでも別の設計条件。現TPU支持は不成立でカバーはシャーシ/ガードと交差する。 | FLベンチに必要な足本体1個を先に版/ソケット/保持で確認する。残り足はRV-06、thigh_capはRV-14/16の採用案後に不足数を確定する。MouthはPR-07へ分離する。<br>証拠: 部品行ごとの1脚試験/残数/保留の記録。足プラグ側を下にした設定と旧版混入防止。全プレート完了をL-01の前提にしない。 | P-04 | [AP-121](additional-purchases.md#ap-121) / [AP-129](additional-purchases.md#ap-129) / [AP-126](additional-purchases.md#ap-126) / [AP-127](additional-purchases.md#ap-127) / [AP-128](additional-purchases.md#ap-128)；[脚骨格・足](additional-printing.md#leg-frame) / [脚装飾](additional-printing.md#leg-shell) / [未採用候補](additional-printing.md#candidates) / [既存3MFと印刷手順](additional-printing.md#plates) |
| [PR-06 #24](https://github.com/hapx2yuki/Tachikoma/issues/24) | OPEN / Blocked<br>現物・実行証拠待ち | Restは実際に8種9個を収録し、肩ブラケット左右/上腕左右は入っていない。首・前腕・眼・カメラ・音声受けが混在し、前腕は現STLと不一致。旧名称から全腕部品が揃うと判断しない。 | 部品別にP-03/P-06/P-07の実測と対応RVの条件を確認し、必要な単体だけ別プレートで1個試す。肩/上腕の不足分は現STLから追加する。pod_neckとeye/cameraは未採用候補を本流へ混ぜない。<br>証拠: 肩/上腕/前腕/爪座/眼受け/カメラ受け/音声受け/首の引渡し台帳。各組立課題は自分の部品行の合格を確認する。 | P-04 | [AP-120](additional-purchases.md#ap-120) / [AP-125](additional-purchases.md#ap-125) / [AP-128](additional-purchases.md#ap-128)；[腕](additional-printing.md#arm) / [頭・カメラ・音声](additional-printing.md#head-camera-audio) / [首・Cabin・意匠](additional-printing.md#cabin-decor) / [未採用候補](additional-printing.md#candidates) / [既存3MFと印刷手順](additional-printing.md#plates) |
| [PR-07 #25](https://github.com/hapx2yuki/Tachikoma/issues/25) | OPEN / Blocked<br>現物・実行証拠待ち | Cannonの挿入路、NeckのBall/Cap座は本流修正済み。Mouth_Neckは現存Blue_2に無く、印刷済みか履歴確認が必要。 | P-06実測とRV-08のキー公差条件を反映し、Cannon/Ball/Neckとmic/spk受けの必要分だけ1組作る。mic受けは必要なら0.12mm層で試し、砲口からの挿入を確認する。<br>証拠: 対象版/数量/設定/写真、旧Neck/Cannonの内部加工可否、H-03へ渡す一式。 | P-06、RV-08 | [AP-120](additional-purchases.md#ap-120) / [AP-094](additional-purchases.md#ap-094)；[頭・カメラ・音声](additional-printing.md#head-camera-audio) / [既存3MFと印刷手順](additional-printing.md#plates) |
| [PR-08 #26](https://github.com/hapx2yuki/Tachikoma/issues/26) | OPEN / Blocked<br>現物・実行証拠待ち | v2ホロー版でもHeadTopと設計基準ケースは597〜1277mm³交差し、既存7タブの頭支持も未成立。現Blue1にはHeadTopが無く標準shin1だけなので、プレート名やv2所持だけでは完了できない。 | P-02で既印刷版を保存し、RV-09の収納とRV-13の支持が決まってから採用STLを確認する。再印刷/既品加工は頭の開閉・目/カメラ/配線を含めて比較する。<br>証拠: 採用版と旧品の差、必要加工/印刷数、頭内隙間・支持・開閉確認。寸法未確定の頭を追加印刷しない。 | P-02、RV-09、RV-13 | [AP-120](additional-purchases.md#ap-120) / [AP-006](additional-purchases.md#ap-006) / [AP-087](additional-purchases.md#ap-087)；[頭・カメラ・音声](additional-printing.md#head-camera-audio) / [未採用候補](additional-printing.md#candidates) / [既存3MFと印刷手順](additional-printing.md#plates) |
| [PR-09 #27](https://github.com/hapx2yuki/Tachikoma/issues/27) | OPEN / Blocked<br>現物・実行証拠待ち | 骨格の再印刷は全数指示ではなくP-05の部品別判断。chassis追加カラーとcoxa内部変更を穴拡張だけで代替できない。 | P-05で確定した変更対象だけ別名3MFで作る。試験品→合格後の不足残数とし、変更していないfemurや配置だけ変わったelbowを自動再印刷しない。<br>証拠: 対象・必要数・旧品再使用の理由とSHA/設定/写真。不要ならP-05の根拠付きで不要完了を記録する。 | P-05 | [AP-003](additional-purchases.md#ap-003) / [AP-006](additional-purchases.md#ap-006) / [AP-125](additional-purchases.md#ap-125) / [AP-128](additional-purchases.md#ap-128)；[脚骨格・足](additional-printing.md#leg-frame) / [腕](additional-printing.md#arm) / [頭・カメラ・音声](additional-printing.md#head-camera-audio) / [既存3MFと印刷手順](additional-printing.md#plates) |
| [PR-10 #79](https://github.com/hapx2yuki/Tachikoma/issues/79) | OPEN / Blocked<br>現物・実行証拠待ち | カメラbaseの旧ポケット差だけでなく、OV2640/OV3660と主基板/FPC保持の選択が未確定。shellを無条件に再使用可とはしない。 | P-07の同定後H-02の採用構成に合うbase/shell/carrierを比較する。旧White_3を即送信せず必要な1組だけ別名保存し、FPCを通した仮組みを優先する。<br>証拠: カメラ版、採用STL、既品再使用/変更、1組の写真と挿入/FOV確認。 | P-07、P-02 | [AP-059](additional-purchases.md#ap-059) / [AP-060](additional-purchases.md#ap-060) / [AP-120](additional-purchases.md#ap-120) / [AP-135](additional-purchases.md#ap-135)；[頭・カメラ・音声](additional-printing.md#head-camera-audio) / [未採用候補](additional-printing.md#candidates) / [既存3MFと印刷手順](additional-printing.md#plates) |
| [PR-11 #86](https://github.com/hapx2yuki/Tachikoma/issues/86) | OPEN / Blocked<br>現物・実行証拠待ち | 残りtibiaはRR標準1、FR/RL鏡像2。FL試験の合格前に3本を追加する根拠はない。 | L-02が同じ版/材/設定で合格した後、不足をP-02で照合して必要分だけ印刷する。材や姿勢を変えた場合は強度と嵌合を再確認する。<br>証拠: 標準1/鏡像2の充足、4壁/40%と向き、SHA/写真、L-03/04/05への引渡し。 | L-02 | [AP-125](additional-purchases.md#ap-125) / [AP-128](additional-purchases.md#ap-128)；[脚骨格・足](additional-printing.md#leg-frame) / [既存3MFと印刷手順](additional-printing.md#plates) |

### 電装

| 課題 | 状態案・進捗 | 現在地／未完理由 | 次の具体作業／完了証拠 | 完了待ち | 購入・印刷 |
|---|---|---|---|---|---|
| [EL-01 #28](https://github.com/hapx2yuki/Tachikoma/issues/28) | OPEN / Ready<br>現物・実行証拠待ち | 外部記録でHENGE UBEC(型番未確認、5/6V・瞬間12A表記)を確認した。連続定格・現物ラベル・設計の10A基準との差、無負荷出力と2S末期の入力余裕は未測定。 | 型番と許容入力をP-01で照合し、サーボ未接続で6.0V/5.0Vを測る。2S→ヒューズ→DC定格SW→二系統、VBAT分圧100k/33k、サーボ電源外部バスを確認する。<br>証拠: 無負荷の電圧、型番/ジャンパ/配線写真と外部遮断試験。電流/発熱/低入力はEL-09へ別記録。 | なし | [AP-009](additional-purchases.md#ap-009) / [AP-013](additional-purchases.md#ap-013) / [AP-029](additional-purchases.md#ap-029) / [AP-030](additional-purchases.md#ap-030) / [AP-031](additional-purchases.md#ap-031) / [AP-036](additional-purchases.md#ap-036) / [AP-037](additional-purchases.md#ap-037) / [AP-038](additional-purchases.md#ap-038) / [AP-039](additional-purchases.md#ap-039) / [AP-040](additional-purchases.md#ap-040) / [AP-041](additional-purchases.md#ap-041) / [AP-042](additional-purchases.md#ap-042) / [AP-043](additional-purchases.md#ap-043) / [AP-046](additional-purchases.md#ap-046) / [AP-048](additional-purchases.md#ap-048) / [AP-049](additional-purchases.md#ap-049)；[首・Cabin・意匠](additional-printing.md#cabin-decor) |
| [EL-02 #29](https://github.com/hapx2yuki/Tachikoma/issues/29) | OPEN / Ready<br>現物・実行証拠待ち | PCA2枚セットは現物未確認で現物確認前。ACK検査はソフト修正済み。現ボードのアドレス/プルアップ/ヘッダ向きと独立OEは実物未確認。ch12の駆動先は無い。 | board0=0x40(脚12)、board1=0x41(腕6/目2)を設定し、ロジック3.3VとSDA/SCLを測る。サーボV+は外部バスへ分岐、信号/GNDを共通化。最終固定はH-06の電装室に合わせる。<br>証拠: 0x40/0x41疎通ログ、表裏写真、プルアップ電圧、OE配線の実測。旧頭中央スタック寸法だけで取付を確定しない。 | なし | [AP-001](additional-purchases.md#ap-001) / [AP-002](additional-purchases.md#ap-002) / [AP-007](additional-purchases.md#ap-007) / [AP-009](additional-purchases.md#ap-009) / [AP-028](additional-purchases.md#ap-028) / [AP-053](additional-purchases.md#ap-053)；[首・Cabin・意匠](additional-printing.md#cabin-decor) |
| [EL-03 #30](https://github.com/hapx2yuki/Tachikoma/issues/30) | OPEN / Ready<br>現物・実行証拠待ち | CALIBRATION_MODEのホスト試験とビルドは合格したが、実ESP32への書込・AP接続・PCA出力は未確認。 | 機体と対象ボードを同定して既存設定/ファームを保全後、校正版をベンチへ書込む。APの実資格情報はローカルだけに置き、USBと外部5Vを同時投入しない。<br>証拠: 書込対象/版・ビルド・起動/I2Cログ、AP画面。サーボ未接続で校正版の中立と低電圧/脱力経路を確認する。 | なし | [AP-007](additional-purchases.md#ap-007) / [AP-009](additional-purchases.md#ap-009) / [AP-012](additional-purchases.md#ap-012) / [AP-016](additional-purchases.md#ap-016) / [AP-027](additional-purchases.md#ap-027) / [AP-063](additional-purchases.md#ap-063)；[印刷一覧](additional-printing.md) |
| [EL-04 #31](https://github.com/hapx2yuki/Tachikoma/issues/31) | OPEN / Blocked<br>現物・実行証拠待ち | 実サーボの中立/方向/可動端は未校正。通常機体は脚12+腕6+目2の20軸で、CH_HEAD予備は通電対象外。 | P-03の許容電圧確認後、リンクを外した1個ずつ1500µsへ合わせる。小刻みなパルスで角度/電流を測り個体番号と軸位相を記録し、500/2500µsへ直接飛ばさない。<br>証拠: 対象脚14/MG90S11/目3の個体表と駆動脚12/腕6/目2への割当・写真・パルス角度表。270度品などは軸別校正とし全軸共通DEG_RANGE変更で混在を隠さない。 | EL-01、EL-02、EL-03、P-03 | [AP-004](additional-purchases.md#ap-004) / [AP-008](additional-purchases.md#ap-008) / [AP-013](additional-purchases.md#ap-013) / [AP-020](additional-purchases.md#ap-020) / [AP-021](additional-purchases.md#ap-021) / [AP-022](additional-purchases.md#ap-022) / [AP-114](additional-purchases.md#ap-114)；[脚骨格・足](additional-printing.md#leg-frame) / [腕](additional-printing.md#arm) / [頭・カメラ・音声](additional-printing.md#head-camera-audio) |
| [EL-05 #32](https://github.com/hapx2yuki/Tachikoma/issues/32) | OPEN / Ready<br>現物・実行証拠待ち | 脚ハーネス12本の実長・端子/線種・導通は未確認。後の軸配置変更があるため最終束ねと長さ確定は本体側で行う。 | AWG16幹線と各枝線/信号を用途別に準備し、電源をPCAへ流さない構成で仮長12本を作る。新しい軸とφ9通路で全可動域の張り/擦れをL-08で確認する。<br>証拠: 12本の線種/仮長/端子極性/導通表と写真。最終切断/束ねは配置確定後と記録。 | なし | [AP-041](additional-purchases.md#ap-041) / [AP-042](additional-purchases.md#ap-042) / [AP-043](additional-purchases.md#ap-043) / [AP-044](additional-purchases.md#ap-044) / [AP-046](additional-purchases.md#ap-046) / [AP-047](additional-purchases.md#ap-047) / [AP-086](additional-purchases.md#ap-086) / [AP-099](additional-purchases.md#ap-099) / [AP-118](additional-purchases.md#ap-118)；[脚骨格・足](additional-printing.md#leg-frame) |
| [EL-06 #33](https://github.com/hapx2yuki/Tachikoma/issues/33) | OPEN / Ready<br>現物・実行証拠待ち | 腕6/目2の電源は外部バスを使う設計。6V適合・実電流と頭内通路は未測定。 | 型番別電圧を確認して8本を余裕長で製作し、電源と信号を区別する。肩/目の最終配置が決まるまで軸根元を固定せず、実可動域で張りを確認する。<br>証拠: 8本の線種/長さ/導通/極性と実取り回し写真。電源電流とPCA基板定格を推測で代用しない。 | なし | [AP-043](additional-purchases.md#ap-043) / [AP-044](additional-purchases.md#ap-044) / [AP-046](additional-purchases.md#ap-046) / [AP-047](additional-purchases.md#ap-047) / [AP-086](additional-purchases.md#ap-086) / [AP-088](additional-purchases.md#ap-088) / [AP-118](additional-purchases.md#ap-118)；[腕](additional-printing.md#arm) / [頭・カメラ・音声](additional-printing.md#head-camera-audio) |
| [EL-07 #34](https://github.com/hapx2yuki/Tachikoma/issues/34) | OPEN / Blocked<br>現物・実行証拠待ち | 通常ビルドは初期脱力→Web「立つ」で20軸を順次通電し、I2C/VBAT故障は停止ラッチする。実ボード動作は未確認。 | CAD全体の確定を待たずサーボ未接続で通常版/AP/UI/故障経路をベンチ確認する。次に校正済み1軸で符号/出力を確かめる。本体荷重試験はL-09の支持台条件へ分離する。<br>証拠: 対象ボード/版のビルド・書込・UIログ、再読込で再通電しない確認、JOINT_SIGN/ARM_SIGN/チャンネル表。 | EL-03 | [AP-007](additional-purchases.md#ap-007) / [AP-008](additional-purchases.md#ap-008) / [AP-012](additional-purchases.md#ap-012) / [AP-016](additional-purchases.md#ap-016) / [AP-027](additional-purchases.md#ap-027) / [AP-063](additional-purchases.md#ap-063)；[印刷一覧](additional-printing.md) |
| [EL-08 #35](https://github.com/hapx2yuki/Tachikoma/issues/35) | OPEN / Blocked<br>現物・実行証拠待ち | DFPlayerと74AHCT125は外部記録に外部記録あり。WS2812×12とmicroSDは記録確認で未確認。LED12/DFPlayerのホスト検証は済んだが、実点灯/再生・5V電流は未測定。 | 74AHCT125を3.3→5V変換に使い、OE/未使用入力を確定してLEDを1灯→12灯で試す。DFPlayerは1kΩ直列とFAT32 SDで再生し、LED0/1..3/4..11の順を記録する。<br>証拠: 12灯動画、DFPlayer再生、5V電圧/電流と使用音源/配線。接続基板を頭内に無理に詰めずH-06へ寸法を渡す。 | EL-07 | [AP-005](additional-purchases.md#ap-005) / [AP-014](additional-purchases.md#ap-014) / [AP-032](additional-purchases.md#ap-032) / [AP-033](additional-purchases.md#ap-033) / [AP-034](additional-purchases.md#ap-034) / [AP-035](additional-purchases.md#ap-035) / [AP-050](additional-purchases.md#ap-050) / [AP-051](additional-purchases.md#ap-051) / [AP-052](additional-purchases.md#ap-052) / [AP-053](additional-purchases.md#ap-053)；[首・Cabin・意匠](additional-printing.md#cabin-decor) / [頭・カメラ・音声](additional-printing.md#head-camera-audio) |
| [EL-09 #75](https://github.com/hapx2yuki/Tachikoma/issues/75) | OPEN / Ready<br>現物・実行証拠待ち | 電源収支はUNVERIFIED。旧9〜14Aは仮定であり、正機械仕事率から保持電流/銅損は求められない。 | EL-01やL-02/L-10の成功/失敗ログから6Vバス、5Vバス、電池入力の電流/電圧/温度を別計測する。入力電力換算とUBEC型番別の連続/瞬間定格、SW/ヒューズ/線材を照合する。<br>証拠: 実型番・負荷/時間・最低入力・ピーク/平均・温度の表と継続/交換の根拠。歩行合格待ちで対策検討を止めず、10A直列テスターを全機へ挿入しない。 | なし | [AP-004](additional-purchases.md#ap-004) / [AP-007](additional-purchases.md#ap-007) / [AP-009](additional-purchases.md#ap-009) / [AP-010](additional-purchases.md#ap-010) / [AP-012](additional-purchases.md#ap-012) / [AP-030](additional-purchases.md#ap-030) / [AP-031](additional-purchases.md#ap-031) / [AP-036](additional-purchases.md#ap-036) / [AP-037](additional-purchases.md#ap-037) / [AP-038](additional-purchases.md#ap-038)；[首・Cabin・意匠](additional-printing.md#cabin-decor) |
| [EL-10 #76](https://github.com/hapx2yuki/Tachikoma/issues/76) | OPEN / Blocked<br>現物・実行証拠待ち | 手動脱力と異常停止は実装済み。自動休止スタンス/支持付き復帰と10分保持温度の比較は未実施。 | 脚の負担が下がる休止姿勢と停止/再開経路をモデルで比較し、足裏/干渉を確認する。実機は支持を確保して現行版と温度を比較し、自動脱力で倒れる条件を除く。<br>証拠: トルク低減量、遷移/再開の検証、10分の実温度・電流比較。未測定の保持割合を定格余裕と扱わない。 | EL-07 | [AP-004](additional-purchases.md#ap-004) / [AP-007](additional-purchases.md#ap-007) / [AP-008](additional-purchases.md#ap-008) / [AP-010](additional-purchases.md#ap-010)；[脚骨格・足](additional-printing.md#leg-frame) / [未採用候補](additional-printing.md#candidates) |

### 脚

| 課題 | 状態案・進捗 | 現在地／未完理由 | 次の具体作業／完了証拠 | 完了待ち | 購入・印刷 |
|---|---|---|---|---|---|
| [L-01 #36](https://github.com/hapx2yuki/Tachikoma/issues/36) | OPEN / Blocked<br>現物・実行証拠待ち | FL標準骨格は片脚試験用。coxaポケット改訂と実サーボ寸法の照合が必要で、全装飾の接着を先行しない。 | PR-04標準tibia1本、P-05で認めたcoxa/femur、校正済みサーボを使う。ケースタブ/ホーン共締め/中心ビスを確認し、足本体1個のソケットと保持を別検品して組む。<br>証拠: 標準FLの版・個体番号・側面/ホーン写真、低速の干渉/ガタ/緩み確認。PR-05のthigh_cap全数待ちは不要、試験用足の充足記録は必須。 | PR-04、EL-04、P-05 | [AP-020](additional-purchases.md#ap-020) / [AP-024](additional-purchases.md#ap-024) / [AP-070](additional-purchases.md#ap-070) / [AP-072](additional-purchases.md#ap-072) / [AP-075](additional-purchases.md#ap-075) / [AP-101](additional-purchases.md#ap-101)；[脚骨格・足](additional-printing.md#leg-frame) |
| [L-02 #37](https://github.com/hapx2yuki/Tachikoma/issues/37) | OPEN / Blocked<br>現物・実行証拠待ち | 1.2kg×水平155mm=18.6kgf·cmは試験条件であり、6Vの連続定格ではない。実保持・発熱・ホーン滑りは未確認。 | 現品の6V対応を確認したうえで6V給電し、coxaを固定し無負荷から段階荷重、電圧/電流/角度/温度を記録する。未確認品へ7.4Vを加えない。条件が安定した場合に155mmのレバーで1.2kgを10秒確認し、白化/割れ/滑り/急増時は除荷する。<br>証拠: レバー長・錘・版/個体が分かる動画と値。10秒合格を連続歩行合格にしない。不合格原因はL-11/EL-09へ戻し、L-03/04/05とPR-11を解放しない。 | L-01、EL-01、EL-03 | [AP-004](additional-purchases.md#ap-004) / [AP-007](additional-purchases.md#ap-007) / [AP-010](additional-purchases.md#ap-010) / [AP-013](additional-purchases.md#ap-013) / [AP-143](additional-purchases.md#ap-143)；[脚骨格・足](additional-printing.md#leg-frame) |
| [L-03 #38](https://github.com/hapx2yuki/Tachikoma/issues/38) | OPEN / Blocked<br>現物・実行証拠待ち | FRはcoxa/femur/tibiaの鏡像_m。現物版・個体の確認とFLゲート合格は未提出。 | L-02/PR-11後、FR用鏡像3点と校正サーボで組む。ホーン共締め・中心ビス・足保持を確認し、装飾は付けず低速で動かす。<br>証拠: FR個体番号/使用版と完成写真、嵌合・ガタ・干渉の記録。RL/RRとは別ベンチで並行可。 | L-02、PR-11 | [AP-020](additional-purchases.md#ap-020) / [AP-024](additional-purchases.md#ap-024) / [AP-070](additional-purchases.md#ap-070) / [AP-075](additional-purchases.md#ap-075)；[脚骨格・足](additional-printing.md#leg-frame) |
| [L-04 #39](https://github.com/hapx2yuki/Tachikoma/issues/39) | OPEN / Blocked<br>現物・実行証拠待ち | RLはcoxa/femur/tibiaの鏡像_m。後脚の最終ポッド側制限は本体取付後に別確認する。 | L-02/PR-11後、RLの鏡像3点を組み、ホーン位相と足ソケットを検査する。後脚配線は余裕を残してL-08へ渡す。<br>証拠: RLの個体/版/写真、無負荷の範囲・配線出口・締結検査。前脚の記録を流用しない。 | L-02、PR-11 | [AP-020](additional-purchases.md#ap-020) / [AP-024](additional-purchases.md#ap-024) / [AP-070](additional-purchases.md#ap-070) / [AP-075](additional-purchases.md#ap-075)；[脚骨格・足](additional-printing.md#leg-frame) |
| [L-05 #40](https://github.com/hapx2yuki/Tachikoma/issues/40) | OPEN / Blocked<br>現物・実行証拠待ち | RRは標準版。残り標準tibia1本の印刷/再使用判断は片脚ゲート後。 | L-02/PR-11後、標準coxa/femur/tibiaとRR割当サーボで組む。FLと同型でも各個体のホーン・ケース・ソケットを確認する。<br>証拠: RRの版/個体表、写真と低速検査。FR/RLの鏡像部品を混ぜない。 | L-02、PR-11 | [AP-020](additional-purchases.md#ap-020) / [AP-024](additional-purchases.md#ap-024) / [AP-070](additional-purchases.md#ap-070) / [AP-075](additional-purchases.md#ap-075)；[脚骨格・足](additional-printing.md#leg-frame) |
| [L-06 #41](https://github.com/hapx2yuki/Tachikoma/issues/41) | OPEN / Blocked<br>現物・実行証拠待ち | 最終の頭内電装配置は未成立。頭無しの外部仮置きは可能だが、旧中央PCA/テープ固定を完成配置とは扱えない。 | P-05で使えるシャーシと4個の中立ヨーサーボを組み、電源/基板は脱着できる頭無し試験配置にする。battery_cradle、配線穴、重量/固定/短絡防止を確認し、最終室はH-06へ分ける。<br>証拠: 仮配置であることを明示した上下写真、4個体/ch表、配線穴の実通し、電池保持。将来のRV-09軸/頭支持変更の影響を記録。 | EL-01、EL-02、EL-04、P-05 | [AP-001](additional-purchases.md#ap-001) / [AP-002](additional-purchases.md#ap-002) / [AP-007](additional-purchases.md#ap-007) / [AP-028](additional-purchases.md#ap-028) / [AP-080](additional-purchases.md#ap-080) / [AP-081](additional-purchases.md#ap-081)；[脚骨格・足](additional-printing.md#leg-frame) / [首・Cabin・意匠](additional-printing.md#cabin-decor) |
| [L-07 #42](https://github.com/hapx2yuki/Tachikoma/issues/42) | OPEN / Blocked<br>現物・実行証拠待ち | 4脚の固定方位はFR15/FL165/RL210/RR330が基準だが、現サーボと実トリムは未確認。 | 本体を無通電で支持し、中立マークと標準FL/RR・鏡像FR/RLを照合してヨーホーンを共締めする。脚同士の隙間を低速で確認し、未解決の頭/腕は付けない。<br>証拠: 4脚上面写真・ホーン締結・個体/ch表と実接地。中立0度と115mm保持指令を同じ姿勢と呼ばない。 | L-01、L-03、L-04、L-05、L-06 | [AP-020](additional-purchases.md#ap-020) / [AP-024](additional-purchases.md#ap-024) / [AP-070](additional-purchases.md#ap-070) / [AP-075](additional-purchases.md#ap-075)；[脚骨格・足](additional-printing.md#leg-frame) |
| [L-08 #43](https://github.com/hapx2yuki/Tachikoma/issues/43) | OPEN / Blocked<br>現物・実行証拠待ち | 12chの配線経路は設計上の案で、実コネクタ径と全可動域の余長は未確認。 | L-07の脚にEL-05のハーネスを仮配線し、電源は外部バス、PCAは信号/GNDへ分ける。FR0/1/2、FL3/4/5、RL6/7/8、RR9/10/11を1本ずつ照合する。<br>証拠: 個体/ch/極性表と全域で張り/擦れ/噛み込みが無い写真。穴が詰まる場合は負荷経路を確認してから再設計する。 | L-07、EL-05 | [AP-044](additional-purchases.md#ap-044) / [AP-046](additional-purchases.md#ap-046) / [AP-047](additional-purchases.md#ap-047) / [AP-081](additional-purchases.md#ap-081) / [AP-082](additional-purchases.md#ap-082) / [AP-088](additional-purchases.md#ap-088)；[脚骨格・足](additional-printing.md#leg-frame) |
| [L-09 #44](https://github.com/hapx2yuki/Tachikoma/issues/44) | OPEN / Blocked<br>現物・実行証拠待ち | 通常版は初期脱力。床上の中立から順次起動する計算は0.454秒で転倒し、実機の起動手順は未確認。 | 支持台で支え、全サーボ外し電圧確認→1個→脚12の段階確認を行う。Web「立つ」で起動後に脚の符号/位相を確認し、立位で支持を下ろす。腕6/目2は単体/後工程で確認し、この頭無し工程のため取付を前倒ししない。<br>証拠: 各段階の電圧/電流、採用Trim/JOINT_SIGN/ARM_SIGN、立位動画。未使用ch12は未接続、USBと外部5Vは排他。 | L-08、EL-07 | [AP-004](additional-purchases.md#ap-004) / [AP-007](additional-purchases.md#ap-007) / [AP-008](additional-purchases.md#ap-008) / [AP-009](additional-purchases.md#ap-009) / [AP-010](additional-purchases.md#ap-010)；[脚骨格・足](additional-printing.md#leg-frame) |
| [L-10 #45](https://github.com/hapx2yuki/Tachikoma/issues/45) | OPEN / Blocked<br>現物・実行証拠待ち | 頭無し実機の立位/歩行は未確認。条件付きの全装備モデルや旧動画を実機合格に置き換えない。 | L-09後に平坦面・115mm/歩幅50%から前進/旋回/停止を試し、電圧/電流/温度を記録する。装飾なしでも硬足が先行するため試験用接触面を記録し、滑りがあれば支持を直す。<br>証拠: 転倒/脱調なしの動画と試験用の質量/足接触/仮電装条件。失敗はEL-09/L-11へ戻し、フルドレスへの合格外挿をしない。 | L-09 | [AP-004](additional-purchases.md#ap-004) / [AP-007](additional-purchases.md#ap-007) / [AP-008](additional-purchases.md#ap-008) / [AP-010](additional-purchases.md#ap-010) / [AP-081](additional-purchases.md#ap-081)；[脚骨格・足](additional-printing.md#leg-frame) / [未採用候補](additional-printing.md#candidates) |
| [L-11 #77](https://github.com/hapx2yuki/Tachikoma/issues/77) | OPEN / Ready<br>現物・実行証拠待ち | DS3218の6V補間19.94kgf·cmは公称ストールの仮定。購入型番と継続保持能力は未確定。 | P-03とL-02の成功/失敗ログを使い、6V運用の歩幅/スタンス/軽量化を先に比較する。力不足を再現した軸だけ、6V適合のケース・連続能力・費用で交換候補を検討する。<br>証拠: 同じ荷重/形状/温度/時間での比較と採用理由。サーボ全14個交換や未同定品への7.4V化を既定にしない。 | なし | [AP-004](additional-purchases.md#ap-004) / [AP-010](additional-purchases.md#ap-010) / [AP-013](additional-purchases.md#ap-013) / [AP-020](additional-purchases.md#ap-020) / [AP-130](additional-purchases.md#ap-130) / [AP-143](additional-purchases.md#ap-143)；[脚骨格・足](additional-printing.md#leg-frame) / [未採用候補](additional-printing.md#candidates) |

### 腕

| 課題 | 状態案・進捗 | 現在地／未完理由 | 次の具体作業／完了証拠 | 完了待ち | 購入・印刷 |
|---|---|---|---|---|---|
| [A-01 #46](https://github.com/hapx2yuki/Tachikoma/issues/46) | OPEN / Blocked<br>現物・実行証拠待ち | 右腕の内部干渉は局所修正済み。固定爪の座/公差が未確定で、肩対前脚の本体干渉は単体腕とは別問題。 | 実測適合した標準shoulder/upper/forearm/claw_mountを部品別に受取り、校正済みMG90Sで組む。肩pitch 0度は水平、校正範囲の基準pitch -45〜85度・肘0〜95度・肘中立45度を照合する。固定爪接着はRV-17の成立後に行う。<br>証拠: 右腕単体の版・P-02/P-05の該当品受入れ・2個体番号・肘0〜95度/ピッチ域の無負荷動画と固定爪保持。PR-06/Gray/Black全プレートの完了待ちは不要。 | EL-04、P-04、RV-17 | [AP-021](additional-purchases.md#ap-021) / [AP-025](additional-purchases.md#ap-025) / [AP-073](additional-purchases.md#ap-073) / [AP-075](additional-purchases.md#ap-075) / [AP-083](additional-purchases.md#ap-083)；[腕](additional-printing.md#arm) / [既存3MFと印刷手順](additional-printing.md#plates) |
| [A-02 #47](https://github.com/hapx2yuki/Tachikoma/issues/47) | OPEN / Blocked<br>現物・実行証拠待ち | 左腕は_L骨格を使用。先行claw_mount_Lは旧3MFに腕7部品を含むため、1個だけ印刷済みと決めつけない。 | P-02で_Lの実在庫/壁数を照合し、実測適合部品を受取る。左もpitch -45〜85度・肘0〜95度・肘中立45度を校正範囲の基準として確認する。爪ハブはArm_Left_Claw_GreyでRV-17の公差確定後に固定する。<br>証拠: 左腕単体の版・P-02/P-05の該当品受入れ・個体・設定と動作/保持写真。右腕との鏡像・ヨー符号を記録し、右の合格を代用しない。 | EL-04、P-04、RV-17 | [AP-021](additional-purchases.md#ap-021) / [AP-025](additional-purchases.md#ap-025) / [AP-073](additional-purchases.md#ap-073) / [AP-075](additional-purchases.md#ap-075) / [AP-083](additional-purchases.md#ap-083)；[腕](additional-printing.md#arm) / [既存3MFと印刷手順](additional-printing.md#plates) |
| [A-03 #48](https://github.com/hapx2yuki/Tachikoma/issues/48) | OPEN / Blocked<br>現物・実行証拠待ち | 停止でも肩pitchケース対前脚pitchケースが約451/413mm³交差する。腕単体の合格だけでは本体へ吊れない。 | RV-09/RV-10の軸/ケース配置を確定しL-07の脚と無通電で仮組みする。右16/17/18、左20/21/22と位相を照合し、TUCK/READY/REACH/WAVEを低速で試す。<br>証拠: 全プリセット・脚停止/遷移の隙間、配線余長、個体/ch/符号と動画。連成ガードはtargetと出力後角で確認する。 | A-01、A-02、L-07、EL-06、EL-07、RV-09、RV-10 | [AP-021](additional-purchases.md#ap-021) / [AP-025](additional-purchases.md#ap-025) / [AP-073](additional-purchases.md#ap-073) / [AP-075](additional-purchases.md#ap-075)；[腕](additional-printing.md#arm) / [脚骨格・足](additional-printing.md#leg-frame) |
| [A-04 #49](https://github.com/hapx2yuki/Tachikoma/issues/49) | OPEN / Blocked<br>現物・実行証拠待ち | 肘殻2個は形状同一で局所Y=-13.8mmへ配置訂正。腕Guardは現表示がRight原型の標準+鏡像、旧印刷表がLeft/Right各1で対応未確定。 | 既印刷elbowを保存し新しい座で仮付けする。arm_pod/GuardはRV-10で原型・左右・取付を確定後、内側支持と脱着を確認して固定する。<br>証拠: 原型名/左右/版の表、肘端と4プリセットの外装写真・隙間・接着保持。Guardを未確認で追加印刷しない。 | A-03 | [AP-073](additional-purchases.md#ap-073) / [AP-083](additional-purchases.md#ap-083) / [AP-088](additional-purchases.md#ap-088)；[腕](additional-printing.md#arm) / [既存3MFと印刷手順](additional-printing.md#plates) |

### 頭・音声・カメラ

| 課題 | 状態案・進捗 | 現在地／未完理由 | 次の具体作業／完了証拠 | 完了待ち | 購入・印刷 |
|---|---|---|---|---|---|
| [H-01 #50](https://github.com/hapx2yuki/Tachikoma/issues/50) | OPEN / Blocked<br>現物・実行証拠待ち | 目ポッドの固定ケース/保持板は頭内の脚yawケースと交差する。目単体の中立/保持/6V適合は現物未確認。 | 校正済み目2個と実測適合carrierを受取り、ホーン共締め2本/目(全4本)で先にポッドへ固定し中立位相を合わせる。現構造では中心ビスに工具が届かないため、軸との保持/着脱は実物で確認する。単体でkyoro/front/scanを確認し、頭へ接着するロールはRV-09の配置後に確定する。<br>証拠: 左右24/26chの個体/パルス/ドット位相・P-02/P-05の該当品受入れ・保持/動作動画。瞬着でスプラインへ不可逆固定する前に着脱と位相を確認。 | EL-04、P-04 | [AP-022](additional-purchases.md#ap-022) / [AP-026](additional-purchases.md#ap-026) / [AP-079](additional-purchases.md#ap-079) / [AP-083](additional-purchases.md#ap-083) / [AP-092](additional-purchases.md#ap-092)；[頭・カメラ・音声](additional-printing.md#head-camera-audio) / [既存3MFと印刷手順](additional-printing.md#plates) |
| [H-02 #51](https://github.com/hapx2yuki/Tachikoma/issues/51) | OPEN / Blocked<br>現物・実行証拠待ち | OV3660用のレンズ座/FPC/主基板トレー候補を作ったが未採用。現カメラ保持板はHeadTopとも約0.542mm³交差する。 | P-07の現品同定後にbase/shell/carrierと主基板/USB/FPCを仮組みする。OV3660で既存瞳10mmを保つ候補は後退≤4.05mmを基準とし、旧6.57mmを流用しない。実品の画角/FPCで再計算し、実接続/撮影・全視野・取り外し・熱・保持を試す。<br>証拠: 採用カメラ版/寸法/画角/経路と撮影画像、消費電流、頭内配置。基板を空き場所へテープ留めしただけで成立としない。 | P-07、PR-10 | [AP-017](additional-purchases.md#ap-017) / [AP-059](additional-purchases.md#ap-059) / [AP-060](additional-purchases.md#ap-060) / [AP-064](additional-purchases.md#ap-064) / [AP-135](additional-purchases.md#ap-135) / [AP-139](additional-purchases.md#ap-139)；[頭・カメラ・音声](additional-printing.md#head-camera-audio) / [未採用候補](additional-printing.md#candidates) |
| [H-03 #52](https://github.com/hapx2yuki/Tachikoma/issues/52) | OPEN / Blocked<br>現物・実行証拠待ち | 砲身の挿入ボア/キー溝とNeck/Cap座は修正済み。実マイク/スピーカーの圧入、8芯通線、音孔位置は未確認。 | P-06/PR-07で認めた部品を仮組みし、micのL/R=GNDと音孔、SPKの向きを確認する。6+2芯をCannon→Neck→Ballへ通し、着脱できる状態で導通を測る。<br>証拠: 挿入前後/音孔/キー/通線の写真、部品版・8芯導通と保持。spkワッシャ1個はPR-06の首/眼完了を待たず部品別に受取る。 | PR-07、P-02、RV-08 | [AP-054](additional-purchases.md#ap-054) / [AP-056](additional-purchases.md#ap-056) / [AP-057](additional-purchases.md#ap-057) / [AP-058](additional-purchases.md#ap-058) / [AP-084](additional-purchases.md#ap-084)；[頭・カメラ・音声](additional-printing.md#head-camera-audio) |
| [H-04 #53](https://github.com/hapx2yuki/Tachikoma/issues/53) | OPEN / Blocked<br>現物・実行証拠待ち | I2S形式/部分書込/取消は修正しホスト試験合格。実音響と手元MAX98357AのSD回路、1W SPKの出力上限は未確認。 | 砲身組込を待たず裸配線でINMP441とMAX98357Aを低音量から試す。GPIO26/25のクロック共有、27出力/33入力と基板別SDを確認し、mock自己検査→PTT→440Hz再生へ進む。<br>証拠: 実録音/再生、基板/配線/音量制限、5V電流とクリップ/過熱の記録。裸試験合格後の筐体内音響はH-03/S-04で再確認。 | EL-07 | [AP-009](additional-purchases.md#ap-009) / [AP-015](additional-purchases.md#ap-015) / [AP-045](additional-purchases.md#ap-045) / [AP-054](additional-purchases.md#ap-054) / [AP-055](additional-purchases.md#ap-055) / [AP-056](additional-purchases.md#ap-056)；[印刷一覧](additional-printing.md) |
| [H-05 #54](https://github.com/hapx2yuki/Tachikoma/issues/54) | OPEN / Blocked<br>現物・実行証拠待ち | Ball/Neck/Capの大きい干渉は内部座で修正済み。Mouth_KeyはCannon約0.275/Cap約0.070mm³の公差未確認が残る。 | RV-08で認めた一式とCap/Key/Pegを部品別に照合し、8芯を残した仮組みで挿入/保持を確かめる。旧standoff値だけを頼りに押込み接着しない。<br>証拠: 使用版と全挿入/保持、音声配線、前方/側面写真。小キーを無理に押して白化させず加工公差を記録。 | H-03、RV-08 | [AP-083](additional-purchases.md#ap-083) / [AP-094](additional-purchases.md#ap-094)；[頭・カメラ・音声](additional-printing.md#head-camera-audio) / [既存3MFと印刷手順](additional-printing.md#plates) |
| [H-06 #55](https://github.com/hapx2yuki/Tachikoma/issues/55) | OPEN / In Progress<br>候補比較済み・全体未成立 | Cabin電装室/棚/着脱Peg候補は局所71項目合格。基板実寸・首/Eye/Ballとの全体干渉・通線/強度は未確定。 | 購入基板・USB/電源端子を実測し、RV-15と境界寸法を共有して部品配置/棚/保守経路を修正する。ESP32/PCA/電源を収め、短FPCのXIAOはH-02の頭内保持へ残す。<br>証拠: 全体干渉・基板挿入/脱着・保持/熱/通線の検査と候補採否。変更質量/重心をI-08、印刷影響をP-05へ渡す。 | なし | [AP-001](additional-purchases.md#ap-001) / [AP-002](additional-purchases.md#ap-002) / [AP-027](additional-purchases.md#ap-027) / [AP-028](additional-purchases.md#ap-028) / [AP-030](additional-purchases.md#ap-030) / [AP-031](additional-purchases.md#ap-031) / [AP-053](additional-purchases.md#ap-053) / [AP-138](additional-purchases.md#ap-138)；[首・Cabin・意匠](additional-printing.md#cabin-decor) / [未採用候補](additional-printing.md#candidates) |
| [H-07 #56](https://github.com/hapx2yuki/Tachikoma/issues/56) | OPEN / Ready<br>停止実装済み・予備端子確認待ち | CH_HEAD/ch12の実駆動物は無く、修正版は常時停止。20軸起動から除外し、SG90等は予備扱い。 | PCA ch12を未接続で維持し、実ボードで出力停止と配線ラベルを確認する。新しい可動部を追加する場合だけ別設計/部品判断へ切り分ける。<br>証拠: 予備維持の決定、ch12未接続写真と出力停止確認。新サーボ購入/架空9g質量を復活させない。 | なし | [AP-006](additional-purchases.md#ap-006) / [AP-087](additional-purchases.md#ap-087)；[頭・カメラ・音声](additional-printing.md#head-camera-audio) |

### 外装

| 課題 | 状態案・進捗 | 現在地／未完理由 | 次の具体作業／完了証拠 | 完了待ち | 購入・印刷 |
|---|---|---|---|---|---|
| [S-01 #57](https://github.com/hapx2yuki/Tachikoma/issues/57) | OPEN / Blocked<br>現物・実行証拠待ち | 首梁とTailJointBlue約3282/Ball約2048mm³が交差する。先端だけにスリーブを被せる旧手順は全長では成立しない。 | RV-15/RV-07の採用形状・通線・強度が決まった後、部品を別受取りし全長の挿入と締結/配線/保守を無通電で確認する。<br>証拠: 採用版/締結長/全長写真、支持荷重と取り外し記録。PR-06全体待ちの代わりに首部品の個別合格を確認する。 | L-06、RV-15、RV-07 | [AP-071](additional-purchases.md#ap-071) / [AP-077](additional-purchases.md#ap-077) / [AP-083](additional-purchases.md#ap-083) / [AP-088](additional-purchases.md#ap-088)；[首・Cabin・意匠](additional-printing.md#cabin-decor) / [未採用候補](additional-printing.md#candidates) |
| [S-02a #58](https://github.com/hapx2yuki/Tachikoma/issues/58) | OPEN / Blocked<br>現物・実行証拠待ち | FL標準脚のthigh_cap/ガード/足支持が未成立。ガードは殻の固体内へ埋まる旧配置のまま接着できない。 | L-10後、RV-06/14/16の足支持・カバー・挿入座をFL標準で照合する。shin_shell標準、M3×40とナット、150%toe3個の版/方向を仮組みする。<br>証拠: FLの外内写真・全域隙間・ガード保持・支持荷重。TPUが支えることを実接触で示し、単一凸包の動画を代用しない。 | L-10、RV-06、RV-14、RV-16 | [AP-076](additional-purchases.md#ap-076) / [AP-078](additional-purchases.md#ap-078) / [AP-083](additional-purchases.md#ap-083) / [AP-126](additional-purchases.md#ap-126) / [AP-140](additional-purchases.md#ap-140)；[脚骨格・足](additional-printing.md#leg-frame) / [脚装飾](additional-printing.md#leg-shell) / [未採用候補](additional-printing.md#candidates) / [既存3MFと印刷手順](additional-printing.md#plates) |
| [S-02b #59](https://github.com/hapx2yuki/Tachikoma/issues/59) | OPEN / Blocked<br>現物・実行証拠待ち | FRは鏡像shin_shell_m。前脚の硬toeはTPUより18.102mm先行し、装飾取付には足支持修正が必要。 | RV-06/14/16の採用座と支持をFR鏡像で確認する。標準部品と混ぜずshin取付、ガードの全挿入、toe3個の150%と根元座を順に仮組みする。<br>証拠: FRの版/方向/外内写真、全域で腕/隣脚と干渉せず支持荷重が想定面に乗る記録。 | L-10、RV-06、RV-14、RV-16 | [AP-076](additional-purchases.md#ap-076) / [AP-078](additional-purchases.md#ap-078) / [AP-083](additional-purchases.md#ap-083) / [AP-126](additional-purchases.md#ap-126) / [AP-140](additional-purchases.md#ap-140)；[脚骨格・足](additional-printing.md#leg-frame) / [脚装飾](additional-printing.md#leg-shell) / [未採用候補](additional-printing.md#candidates) / [既存3MFと印刷手順](additional-printing.md#plates) |
| [S-02c #60](https://github.com/hapx2yuki/Tachikoma/issues/60) | OPEN / Blocked<br>現物・実行証拠待ち | RLは鏡像shin_shell_m。後脚は硬toeがTPUより22.034mm先行し、ポッド側の可動域も要確認。 | 採用済みの足/ガード/カバーをRL鏡像に照合し、150%toe3個とM3貫通締結を仮組みする。ポッド側クランプと停止/旋回で首/Cabinへの隙間を測る。<br>証拠: RLの接触/全域隙間/締結/挿入写真。FRの鏡像部品と同形でも後方配置の結果を別記録にする。 | L-10、RV-06、RV-14、RV-16 | [AP-076](additional-purchases.md#ap-076) / [AP-078](additional-purchases.md#ap-078) / [AP-083](additional-purchases.md#ap-083) / [AP-126](additional-purchases.md#ap-126) / [AP-140](additional-purchases.md#ap-140)；[脚骨格・足](additional-printing.md#leg-frame) / [脚装飾](additional-printing.md#leg-shell) / [未採用候補](additional-printing.md#candidates) / [既存3MFと印刷手順](additional-printing.md#plates) |
| [S-02d #61](https://github.com/hapx2yuki/Tachikoma/issues/61) | OPEN / Blocked<br>現物・実行証拠待ち | RRは標準shin_shell。標準FLと同じ部品でも後脚の支持/首干渉条件は異なる。 | RV-06/14/16後にRR標準でガードの挿入・150%toe・足支持を仮組みし、停止から後脚旋回まで検査する。<br>証拠: RRの使用版、外内写真、ポッド側隙間・足反力・固定方法。4脚全体の共面性確認へ値を渡す。 | L-10、RV-06、RV-14、RV-16 | [AP-076](additional-purchases.md#ap-076) / [AP-078](additional-purchases.md#ap-078) / [AP-083](additional-purchases.md#ap-083) / [AP-126](additional-purchases.md#ap-126) / [AP-140](additional-purchases.md#ap-140)；[脚骨格・足](additional-printing.md#leg-frame) / [脚装飾](additional-printing.md#leg-shell) / [未採用候補](additional-printing.md#candidates) / [既存3MFと印刷手順](additional-printing.md#plates) |
| [S-03 #62](https://github.com/hapx2yuki/Tachikoma/issues/62) | OPEN / Blocked<br>現物・実行証拠待ち | HeadTopケース収納・7穴支持が未成立。Head_Plate/Head_Bottom_Capは不採用。旧頭中央PCAとcarrier現物合わせ接着を既定にしない。 | RV-09/RV-13とH-01/H-02/H-06の採用配置で頭上下を仮組みする。目/カメラ/FPC/配線・開閉・固定受けを確認し、S-08で位置・受け座・挿入が成立した装飾だけ固定する。<br>証拠: 合わせ目・支持/締結長・全ヨー隙間・眼動画/カメラ画像・取り外し手順。確認済み頭装飾の個別引渡しで進める。 | H-01、H-02、H-06、PR-08、L-10、RV-09、RV-13、S-08 | [AP-006](additional-purchases.md#ap-006) / [AP-083](additional-purchases.md#ap-083) / [AP-087](additional-purchases.md#ap-087) / [AP-088](additional-purchases.md#ap-088)；[頭・カメラ・音声](additional-printing.md#head-camera-audio) / [首・Cabin・意匠](additional-printing.md#cabin-decor) / [未採用候補](additional-printing.md#candidates) |
| [S-04 #63](https://github.com/hapx2yuki/Tachikoma/issues/63) | OPEN / Blocked<br>現物・実行証拠待ち | 口とシャーシの挿入363姿勢は合格したが、実通線・接着/保持・装着後音響は未確認。 | H-05の一式をS-03へ仮取付し、8芯が受け穴を通ることと採用した-18度基準姿勢を確認する。Ball保持と腕の全プリセット隙間を測り、PTT/再生を再試験する。<br>証拠: 正面/側面/配線写真、保持方法、腕隙間と筐体内音声動画。スナップ成立を公称径だけで決めない。 | H-05、S-03 | [AP-054](additional-purchases.md#ap-054) / [AP-056](additional-purchases.md#ap-056) / [AP-057](additional-purchases.md#ap-057) / [AP-058](additional-purchases.md#ap-058) / [AP-083](additional-purchases.md#ap-083)；[頭・カメラ・音声](additional-printing.md#head-camera-audio) |
| [S-05 #64](https://github.com/hapx2yuki/Tachikoma/issues/64) | OPEN / Blocked<br>現物・実行証拠待ち | CabinBackは6.3075mm下げてPegを整合した。電装室/首/Eyeの干渉が残り、Front/Backの最終接着はできない。 | H-06/RV-15で採用した内部と接合部を使い、欠品意匠/LEDを個別に受け取る。非対称特徴で向きを確認し、基板・通線・保守を試してから外装を固定する。<br>証拠: 向きの根拠、Peg/目/装飾の座、開閉と電装収納、LED写真。所在不明の元Downloads3MFを再確認済みとは記さない。 | H-06、RV-15 | [AP-033](additional-purchases.md#ap-033) / [AP-083](additional-purchases.md#ap-083) / [AP-085](additional-purchases.md#ap-085) / [AP-106](additional-purchases.md#ap-106)；[首・Cabin・意匠](additional-printing.md#cabin-decor) / [未採用候補](additional-printing.md#candidates) / [既存3MFと印刷手順](additional-printing.md#plates) |
| [S-06 #65](https://github.com/hapx2yuki/Tachikoma/issues/65) | OPEN / Blocked<br>現物・実行証拠待ち | 首/Cabinの通線と全長装飾、印刷強度が未成立。旧「フランジ穴を現物合わせで開けて完成」は根拠不足。 | S-01/S-05の採用部を無通電で合わせ、支持フランジ/当て板/ねじ長と通線経路を検査する。電装を取り外せる順序を保ち、仮支持で段階荷重する。<br>証拠: 取付高さ/後脚隙間/荷重とたわみ・配線/保守写真。対角2脚だけで不安定に持ち上げず、支持台や秤で重心確認へ引継ぐ。 | S-05、S-01 | [AP-071](additional-purchases.md#ap-071) / [AP-077](additional-purchases.md#ap-077) / [AP-138](additional-purchases.md#ap-138)；[首・Cabin・意匠](additional-printing.md#cabin-decor) / [未採用候補](additional-printing.md#candidates) |
| [S-07 #66](https://github.com/hapx2yuki/Tachikoma/issues/66) | OPEN / Blocked<br>現物・実行証拠待ち | LED/DFPlayerの最終位置と5V余裕は未測定。頭内の空きへ追加基板を置く旧案は採用できない。 | EL-08の検証済み配線をH-06の電装室へ収め、LED0〜11を実番号で照合する。5V全負荷、熱、音声との同時動作、首通線と保守開閉を確認する。<br>証拠: 全灯/再生動画、各番号/配線表、5V電流/電圧/温度。I-01の完成重量へ基板と線材を含める。 | EL-08、S-03、S-06 | [AP-005](additional-purchases.md#ap-005) / [AP-032](additional-purchases.md#ap-032) / [AP-033](additional-purchases.md#ap-033) / [AP-034](additional-purchases.md#ap-034) / [AP-035](additional-purchases.md#ap-035) / [AP-052](additional-purchases.md#ap-052) / [AP-085](additional-purchases.md#ap-085)；[首・Cabin・意匠](additional-printing.md#cabin-decor) / [頭・カメラ・音声](additional-printing.md#head-camera-audio) |
| [S-08 #67](https://github.com/hapx2yuki/Tachikoma/issues/67) | OPEN / Ready<br>現物・実行証拠待ち | Head_Insert4個のうち2個の位置が未確定。既存の実測ラベル付きInsert1もHeadTopと128.245mm³、推定Insert2は32.822mm³、推定Screw2は8.723mm³交差する。Screw1も腕ヨーケースと5.400mm³交差しRV-09で追跡中。 | 所有する実物写真/元3MFの取得可能性を確認し、位置だけでなく全Insert/Screwの受け座・挿入・ケース隙間を原型で検査する。実測座標ラベルを嵌合合格とせず、成立した採用形状だけJSON/表示/URDFへ反映する。<br>証拠: 正面/側面/上面の一次写真、採用座標/数量、全受け座と挿入/保持の根拠、または不採用の明示判断。S-03へ確認済み品だけ渡し機体のベンチ試験は止めない。 | なし | [AP-083](additional-purchases.md#ap-083) / [AP-094](additional-purchases.md#ap-094)；[頭・カメラ・音声](additional-printing.md#head-camera-audio) / [首・Cabin・意匠](additional-printing.md#cabin-decor) |

### 統合

| 課題 | 状態案・進捗 | 現在地／未完理由 | 次の具体作業／完了証拠 | 完了待ち | 購入・印刷 |
|---|---|---|---|---|---|
| [I-01 #68](https://github.com/hapx2yuki/Tachikoma/issues/68) | OPEN / Blocked<br>現物・実行証拠待ち | 現行URDF推定質量は2.726350kg。旧2.78/3.0kgは実測重量ではなく、採用予定電装室/支持候補で今後変わる。 | Mouth/LED/配線を含む全装備の実重量を測り、支持台と複数秤で前後左右の荷重を記録する。CG_XY/TOTAL_KGを実測へ更新し、移動する電池位置を保持/配線制約内で比較する。<br>証拠: 電池込み総重量/内訳・秤配置/支持荷重・重心の計算と設定差分。I-08/L-11へ同じ入力を渡す。 | S-03、S-04、S-06、S-07、A-04、S-02a、S-02b、S-02c、S-02d | [AP-011](additional-purchases.md#ap-011)；[首・Cabin・意匠](additional-printing.md#cabin-decor) / [未採用候補](additional-printing.md#candidates) |
| [I-02 #69](https://github.com/hapx2yuki/Tachikoma/issues/69) | OPEN / Blocked<br>現物・実行証拠待ち | フルドレス実歩行は未実施。現足のTPU反力0%、自己干渉ありのため条件付きモデルだけで合格にできない。 | I-01/RV-06/RV-07と設計の干渉修正後、支持台から115mm/歩幅50%で開始する。前後/横/旋回/停止再開を段階的に試し、20軸Trimと電源/温度/電池を記録する。<br>証拠: 実動画・採用形状/サーボ/足材/床・連続時間・電圧/電流/温度・姿勢の記録。転倒や飽和を別件として残す。 | I-01、L-10、I-08、RV-06、RV-07 | [AP-004](additional-purchases.md#ap-004) / [AP-007](additional-purchases.md#ap-007) / [AP-008](additional-purchases.md#ap-008) / [AP-010](additional-purchases.md#ap-010)；[脚骨格・足](additional-printing.md#leg-frame) / [未採用候補](additional-printing.md#candidates) |
| [I-03 #70](https://github.com/hapx2yuki/Tachikoma/issues/70) | OPEN / Blocked<br>現物・実行証拠待ち | voice_bridgeのmock/ホスト通信は検証済み。実マイク往復・テザリング・外部API/音声の利用結果は未確認。 | H-04の裸ベンチで2.4GHz STA/mDNSまたは実IPを確認し、ローカル環境変数でAPIを設定してPTT会話する。API/音声権利と公開範囲を選び、秘密値をIssueへ貼らない。<br>証拠: PTT→応答の動画、往復遅延/切断復帰・使用設定の非秘密情報。Mouth装着待ちでネットワーク検証を止めず、装着後はS-04で再確認。 | H-04 | [AP-054](additional-purchases.md#ap-054) / [AP-055](additional-purchases.md#ap-055) / [AP-056](additional-purchases.md#ap-056)；[頭・カメラ・音声](additional-printing.md#head-camera-audio) |
| [I-04 #71](https://github.com/hapx2yuki/Tachikoma/issues/71) | OPEN / Blocked<br>現物・実行証拠待ち | カメラ連携のHTTP境界はホスト検証したが、実XIAOの撮影と会話応答は未確認。 | H-02のカメラを同じネットワークへ接続し、capture URLと形式を確認する。voice_bridgeのcamera-urlで既知対象を撮り、画像内容と応答を比較する。<br>証拠: 使用カメラ版/FOV・取得画像と対応会話・遅延/タイムアウトの記録。連続映像を静止画として無期限受信しない。 | H-02、I-03 | [AP-017](additional-purchases.md#ap-017) / [AP-059](additional-purchases.md#ap-059) / [AP-064](additional-purchases.md#ap-064)；[頭・カメラ・音声](additional-printing.md#head-camera-audio) / [未採用候補](additional-printing.md#candidates) |
| [I-05 #72](https://github.com/hapx2yuki/Tachikoma/issues/72) | OPEN / Blocked<br>現物・実行証拠待ち | 目/LED/DFPlayer/腕の同時演出は実機未確認。旧「腕退避が半分未満なら正常」という割合は普遍的判定ではない。 | 全装備歩行条件で目モード/方向バイアス、LED番号、起動/歩行音、腕WAVEを順に確認する。脚のtarget/実出力角に応じた退避を記録し干渉/電源余裕を見る。<br>証拠: 演出と歩行が同時に分かる動画、20軸/ch12未使用、電圧/電流と異常の有無。固定割合で保護の成否を判定しない。 | S-07、I-02 | [AP-021](additional-purchases.md#ap-021) / [AP-022](additional-purchases.md#ap-022) / [AP-033](additional-purchases.md#ap-033) / [AP-034](additional-purchases.md#ap-034)；[腕](additional-printing.md#arm) / [頭・カメラ・音声](additional-printing.md#head-camera-audio) / [首・Cabin・意匠](additional-printing.md#cabin-decor) |
| [I-06 #73](https://github.com/hapx2yuki/Tachikoma/issues/73) | OPEN / In Progress<br>監査文書反映済み・製作知見待ち | 監査・配線・製作影響の文書は更新済み。現物の採寸・加工・組立で新たに得た知見はまだ無い。 | 課題ごとに実測値/使用版/写真が出た時点でassembly/wiring/print_manifest/HANDOFFへ反映する。今回の購入・印刷一覧と全107課題のリンクを保守する。<br>証拠: Refs付き変更記録、実測日/出典/未検証の区別、製作手順のリンク確認。監査文書の更新だけで将来の実物知見を完了扱いにしない。 | なし | [購入一覧](additional-purchases.md)；[既存3MFと印刷手順](additional-printing.md#plates) |
| [I-08 #78](https://github.com/hapx2yuki/Tachikoma/issues/78) | OPEN / In Progress<br>設計基準の検証済み・実測反映待ち | 89条件・18姿勢・16回帰と入力一致は実施済み。基本71は58合格/2不合格/3転倒/8初期接触不成立。設計基準ケースと対象個体の一致は未確認。 | P-03等の実測と採用CADを取り込み、STL→URDF→全条件を同じ入力で再実行する。自己干渉/材料別反力・20軸出力・速度トルク・刻み感度を保持し、実機の摩擦/電流/温度へ照合する。<br>証拠: 実購入版での入力SHA、全条件/失敗・警告、実積分qpos動画と実測照合。平地58合格を頭収納/足支持/強度の合格へ拡張しない。 | なし | [AP-004](additional-purchases.md#ap-004) / [AP-010](additional-purchases.md#ap-010) / [AP-011](additional-purchases.md#ap-011) / [AP-012](additional-purchases.md#ap-012)；[未採用候補](additional-printing.md#candidates) / [脚骨格・足](additional-printing.md#leg-frame) / [頭・カメラ・音声](additional-printing.md#head-camera-audio) |
| [I-07 #74](https://github.com/hapx2yuki/Tachikoma/issues/74) | OPEN / Blocked<br>現物・実行証拠待ち | 公開済みの動画は物理計算の条件付き例。完成実機の写真・歩行/会話/カメラ映像は未取得。 | 実機のI-02/I-03/I-04/I-05結果が揃ってから正面/側面/上面と機能動画を撮る。READMEへ使用条件と協力者を記録し、途中の計算映像は表示を分ける。<br>証拠: 完成実機の媒体とREADME変更、全機能の実行根拠。計算結果を実機完成の紹介に使わない。 | I-02、I-03、I-04、I-05、I-06 | [購入一覧](additional-purchases.md)；[既存3MFと印刷手順](additional-printing.md#plates) |

### 是正・検査

| 課題 | 状態案・進捗 | 現在地／未完理由 | 次の具体作業／完了証拠 | 完了待ち | 購入・印刷 |
|---|---|---|---|---|---|
| [RV-01 #81](https://github.com/hapx2yuki/Tachikoma/issues/81) | CLOSED / Done<br>完了（ソフト修正・検証） | 操作画面、低電圧/0V、I2C書込、腕脚ガード、ch12除外、I2S/通信取消を修正。通常/校正ビルドと実コード故障注入は完了し#81はClosed。 | 完了を維持する。実書込/符号/中立はEL-03/EL-07/L-09、実音響はH-04、CPU/I2C断時の独立停止はRV-11へ引継ぐ。<br>証拠: 保存済み修正前再現・ホスト/ビルド・1563フレーム照合の固定記録。新しい実機完了をこのCloseへ混ぜない。 | なし | [AP-007](additional-purchases.md#ap-007)；[印刷一覧](additional-printing.md) |
| [RV-02 #82](https://github.com/hapx2yuki/Tachikoma/issues/82) | CLOSED / Done<br>完了（3MF検査・生成修正） | 27個の3MF比較と生成コード修正を完了し#82はClosed。9個不一致、形状変更10/配置変更2、原型/旧媒体の保持を記録した。 | 完了を維持し、現物版の照合をP-02、加工/再印刷をP-05へ渡す。新しい腕Guardの原型対応はRV-10/PR-01で追跡し旧監査完了範囲を広げない。<br>証拠: 保存された比較/負例/保持SHAと個別引継ぎ。旧3MFを一括上書きせず、実印刷なしと明示。 | なし | [AP-116](additional-purchases.md#ap-116)；[既存3MFと印刷手順](additional-printing.md#plates) / [腕](additional-printing.md#arm) |
| [RV-03 #83](https://github.com/hapx2yuki/Tachikoma/issues/83) | CLOSED / Done<br>完了（検査器の失敗検出） | NG/例外を非0終了へ修正して#83はClosed。53回帰は合格し、最終8NG/1未検証を失敗として保存した。 | 完了を維持し、新しい検査を追加する時は空/NaN/例外/保存失敗の負例を既存回帰へ追加する。現行部品NGは対応RVで修正する。<br>証拠: 負例と正常経路の回帰ログ、非0判定を維持した最終検査記録。NGを消すための閾値緩和をしない。 | なし | [購入一覧](additional-purchases.md)；[既存3MFと印刷手順](additional-printing.md#plates) |
| [RV-04 #84](https://github.com/hapx2yuki/Tachikoma/issues/84) | CLOSED / Done<br>完了（同期処理修正） | 既存Status/担当/コメント保持、冪等同期、対象限定と依存検査を修正して#84はClosed。監査時107課題173依存の照合を保存した。 | 完了を維持する。今回の107件の本文/新依存はdry-run→同期→全件照合し、既存Closed5件と担当/コメントを保持する。進捗変更は今回の明示範囲だけに限定する。<br>証拠: 同期回帰と本文/関係/状態の全件比較、再実行差分0。保存された旧173依存の履歴を最新値へ書換えない。 | なし | [購入一覧](additional-purchases.md)；[既存3MFと印刷手順](additional-printing.md#plates) |
| [RV-05 #85](https://github.com/hapx2yuki/Tachikoma/issues/85) | OPEN / Blocked<br>監査実施済み・全体判定未達 | 生成3工程・23検査・89物理条件を記録したが、23検査は14合格/8NG/1未検証。全体合格のゲートは未達。 | RV-06/07を含む各機構/電装の採用案と実測が出揃った版で、生成→全検査→物理計算を再実行する。購入/印刷の影響と下流実機条件を全課題へ反映する。<br>証拠: 同一版の全検査表と未解決なしの設計判定、必要な実測ゲートの合格根拠。未解決の設計/実測が残る間はOPENを維持し、次の是正を記録しただけではCloseしない。 | RV-01、RV-02、RV-03、RV-04、I-08、RV-06、RV-07、RV-08、RV-09、RV-10、RV-11、RV-12、RV-13、RV-14、RV-15、RV-16、RV-17、H-06 | [AP-004](additional-purchases.md#ap-004) / [AP-007](additional-purchases.md#ap-007) / [AP-010](additional-purchases.md#ap-010) / [AP-094](additional-purchases.md#ap-094)；[未採用候補](additional-printing.md#candidates) / [既存3MFと印刷手順](additional-printing.md#plates) |
| [RV-06 #87](https://github.com/hapx2yuki/Tachikoma/issues/87) | OPEN / In Progress<br>候補比較済み・実支持未成立 | 150%toeではTPUより前18.102/後22.034mm先行、材料別計算のTPU荷重0%。未採用の1.5mm靴候補4条件はTPU支持99.79〜99.92%。 | 取付角/隠し座/着脱支持を比較し、採用候補1脚で摩擦・圧縮・保持・外観を確認する。全到達姿勢の支持と接触を再計算し、現物トゥ根元座も照合する。<br>証拠: 足裏先行/反力/たわみ/接着の実測、外観比較と採否、同じ形状の全回帰。toe無しベンチ合格を全装備支持へ流用しない。 | なし | [AP-126](additional-purchases.md#ap-126) / [AP-127](additional-purchases.md#ap-127) / [AP-140](additional-purchases.md#ap-140)；[脚骨格・足](additional-printing.md#leg-frame) / [脚装飾](additional-printing.md#leg-shell) / [未採用候補](additional-printing.md#candidates) |
| [RV-07 #88](https://github.com/hapx2yuki/Tachikoma/issues/88) | OPEN / In Progress<br>感度検証済み・印刷強度未確認 | 中実断面の合格は4壁/40%印刷を保証しない。首の近似安全率2.71は要求3未満で、腕2壁/15%の過去3MFもある。 | P-02の使用材/向き/壁/充填を確認し、同条件試験片または既印刷品を仮支持で段階荷重する。RV-15の首通線/補強案とケース/ねじ/層方向を連携評価する。<br>証拠: 荷重/たわみ/残留変形/層割れ/締結の実測と採用条件。サーボ保持のL-02と材料強度を別記録にする。 | なし | [AP-010](additional-purchases.md#ap-010) / [AP-011](additional-purchases.md#ap-011) / [AP-125](additional-purchases.md#ap-125) / [AP-126](additional-purchases.md#ap-126) / [AP-143](additional-purchases.md#ap-143)；[脚骨格・足](additional-printing.md#leg-frame) / [腕](additional-printing.md#arm) / [首・Cabin・意匠](additional-printing.md#cabin-decor) / [未採用候補](additional-printing.md#candidates) |
| [RV-08 #89](https://github.com/hapx2yuki/Tachikoma/issues/89) | OPEN / In Progress<br>主要干渉修正済み・キー公差待ち | マイク挿入/Neck球面座/Cap座/シャーシ逃げと支持カラーは修正し挿入363姿勢を検査。Mouth_Keyの微小重なりと実保持公差は残る。 | Cannon/Cap対Keyの深さと現印刷公差を測り、見えない座を最小修正する。P-06の実部品を入れた全挿入/通線を確認し、前タブ+3mmの締結条件をRV-13へ渡す。<br>証拠: 小キーの公差/保持を含む全体組立検査、単一閉体/残肉と旧品加工可否。実音響はH-04へ分離し局所修正だけでCloseしない。 | なし | [AP-054](additional-purchases.md#ap-054) / [AP-055](additional-purchases.md#ap-055) / [AP-056](additional-purchases.md#ap-056) / [AP-057](additional-purchases.md#ap-057) / [AP-058](additional-purchases.md#ap-058) / [AP-094](additional-purchases.md#ap-094)；[頭・カメラ・音声](additional-printing.md#head-camera-audio) / [既存3MFと印刷手順](additional-printing.md#plates) |
| [RV-09 #90](https://github.com/hapx2yuki/Tachikoma/issues/90) | OPEN / In Progress<br>有限探索済み・収納未成立 | 旧検査のケース上方11mmは誤りで、タブ下ケース約28mmが上へ入る。HeadTopと各基準ケース597〜1277mm³、梁89.23mm³等が交差し有限探索は未成立。 | P-03/P-07の実購入寸法を採用前に照合し、既存脚リンク/外観を保つ軸/高さ/向きと目・カメラの同時配置を比較する。ケースを殻の凸包外に出す案は内部削りで成立扱いにしない。<br>証拠: 全ケース/眼/基板/梁の同時成立、壁厚/挿入/工具/配線の根拠と採否。固定軸をRV-13/14/10へ渡し有限失敗を不可能の証明と呼ばない。 | なし | [AP-020](additional-purchases.md#ap-020) / [AP-021](additional-purchases.md#ap-021) / [AP-022](additional-purchases.md#ap-022) / [AP-059](additional-purchases.md#ap-059) / [AP-094](additional-purchases.md#ap-094)；[頭・カメラ・音声](additional-printing.md#head-camera-audio) / [未採用候補](additional-printing.md#candidates) |
| [RV-10 #91](https://github.com/hapx2yuki/Tachikoma/issues/91) | OPEN / In Progress<br>局所修正済み・ケース/Guard未解決 | 腕1664姿勢とcoxa約199万組の局所修正は合格。肩pitch対前脚pitch約451/413mm³は残る。腕Guardは表示Right×2(鏡像)と旧Left/Right各1が不一致。 | RV-09と軸境界を合わせ肩/前脚ケースを同時に成立させる。Guard原型/左右/実印刷と取付位相を独立確認し、必要な表示/CAD/印刷一覧修正を行う。固定手はRV-17、脚カバーはRV-14へ分ける。<br>証拠: 本体の全到達姿勢・外装/Guardを含む干渉0、公差/残肉/工具の根拠、旧品への影響。局所合格を全体合格にしない。 | なし | [AP-021](additional-purchases.md#ap-021) / [AP-025](additional-purchases.md#ap-025) / [AP-094](additional-purchases.md#ap-094)；[腕](additional-printing.md#arm) / [脚骨格・足](additional-printing.md#leg-frame) / [既存3MFと印刷手順](additional-printing.md#plates) |
| [RV-11 #92](https://github.com/hapx2yuki/Tachikoma/issues/92) | OPEN / In Progress<br>文書/ソフト修正済み・現物条件待ち | 部品資料、電源換算、USB排他、LED/PCA電圧とI2S記述は訂正済み。対象個体/保持電流/温度・独立OE/遮断・SPK上限は未確認。 | P-01/P-03と実ラベルを照合し、EL-09で三系統の実電力を測る。CPU/I2C故障中のPWM残留を想定して独立停止を実配線で検証し、MAX98357AのSD/ゲインを実基板に合わせる。<br>証拠: 型番/電源/独立停止/音声基板別の実測表。PM7aで電流を測った扱いにせず、ソフト故障注入を電源遮断保証としない。 | なし | [AP-004](additional-purchases.md#ap-004) / [AP-007](additional-purchases.md#ap-007) / [AP-009](additional-purchases.md#ap-009) / [AP-030](additional-purchases.md#ap-030) / [AP-031](additional-purchases.md#ap-031) / [AP-036](additional-purchases.md#ap-036) / [AP-052](additional-purchases.md#ap-052)；[首・Cabin・意匠](additional-printing.md#cabin-decor) / [頭・カメラ・音声](additional-printing.md#head-camera-audio) |
| [RV-12 #93](https://github.com/hapx2yuki/Tachikoma/issues/93) | CLOSED / Done<br>完了（表示/出力/全件記録） | 表示/変換/STL入出力・515ファイル確認を完了し#93はClosed。内壁保持・退化面・旧出力保護の回帰を保存した。 | 完了を維持する。追加発見の腕Guard原型/左右対応はRV-10とPR-01/A-04で追跡し、その修正後に表示/URDF回帰を追加する。元完了記録の対象範囲を広げない。<br>証拠: 既存監査コミットの検証記録と新追跡先。全1898組中99組の体積共有を検査完了と組立合格で混同しない。 | なし | [購入一覧](additional-purchases.md)；[腕](additional-printing.md#arm) / [既存3MFと印刷手順](additional-printing.md#plates) |
| [RV-13 #94](https://github.com/hapx2yuki/Tachikoma/issues/94) | OPEN / Blocked<br>支持候補比較済み・軸確定待ち | 現行半径78mmの7穴軸は全てHeadTopへ届かず、49候補も後柱とケースが交差。前タブには+3mmカラーを追加済み。 | RV-09の軸/ケース確定後に支持数・柱/受け座・開閉を設計する。前タブ増厚に合うねじ長、締結/工具/配線と残肉を照合し、可視面を保つ候補を比較する。<br>証拠: 全支持の荷重経路・ねじ長/個数・引抜き/層割れ/開閉試験と旧chassisの補強/再印刷判断。 | RV-09 | [AP-006](additional-purchases.md#ap-006) / [AP-070](additional-purchases.md#ap-070) / [AP-087](additional-purchases.md#ap-087)；[頭・カメラ・音声](additional-printing.md#head-camera-audio) / [未採用候補](additional-printing.md#candidates) |
| [RV-14 #95](https://github.com/hapx2yuki/Tachikoma/issues/95) | OPEN / Blocked<br>交差再現済み・軸確定待ち | 停止でchassis対thigh_cap前約99/133、後405/413mm³が交差。coxa対capとthigh_guardも残り、取付耳だけ削れば直る条件ではない。 | RV-09の軸確定後、実C++停止/歩容/遷移でシャーシ・耳・カバーの隙間を比較する。頭支持/電池/ねじ/配線と同時に確認し、可視カバー切削案は先に面積と形を示す。<br>証拠: 全到達姿勢の実交差/残肉/支持の記録、RV-16の挿入座と整合、旧印刷品の再使用/加工/再印刷判断。 | RV-09 | [AP-094](additional-purchases.md#ap-094) / [AP-125](additional-purchases.md#ap-125)；[脚装飾](additional-printing.md#leg-shell) / [未採用候補](additional-printing.md#candidates) |
| [RV-15 #96](https://github.com/hapx2yuki/Tachikoma/issues/96) | OPEN / In Progress<br>全長交差再現済み・候補未採用 | 首とTailJoint全長、CabinFront/Eye/Ballの大きい重なりが残る。局所71項目合格の電装室も全体成立ではない。 | H-06と首フランジ/通線径/電装取り出し境界を共有し、外形を保つ内側加工・支持・挿入を比較する。RV-07の印刷強度とφ8通線案を同じ形状で評価する。<br>証拠: 首/Cabin/Eye/装飾/電装の全体交差と挿入・通線・保守・段階荷重の記録。既存11候補を採用済みとしない。 | なし | [AP-071](additional-purchases.md#ap-071) / [AP-077](additional-purchases.md#ap-077) / [AP-088](additional-purchases.md#ap-088) / [AP-138](additional-purchases.md#ap-138)；[首・Cabin・意匠](additional-printing.md#cabin-decor) / [未採用候補](additional-printing.md#candidates) |
| [RV-16 #97](https://github.com/hapx2yuki/Tachikoma/issues/97) | OPEN / In Progress<br>6案比較済み・受け座未成立 | 大腿81.127%/脛77.940%が旧配置で埋没。0.10/0.15mm座は26方向で挿入できず、開放案は可視面切除や脛分離で不採用。 | 元ガードの見える形状を保ち、殻の分割/着脱/挿入座を比較する。骨格・M3座・工具経路と全挿入軌跡を検査しRV-14の座標と共有する。<br>証拠: 閉体だけでなく組立可能な入口/経路・保持/残肉、外観比較と採否。未採用候補をPR-01/PR-05へ量産指示しない。 | なし | [AP-083](additional-purchases.md#ap-083) / [AP-094](additional-purchases.md#ap-094)；[脚装飾](additional-printing.md#leg-shell) / [未採用候補](additional-printing.md#candidates) |
| [RV-17 #98](https://github.com/hapx2yuki/Tachikoma/issues/98) | OPEN / In Progress<br>手内部検査済み・嵌合未確認 | 片腕のmount/Claw約4.628、Claw/指飾り15.879、指/指飾り17.071mm³が重なる。旧50mm³未満許容を撤回し手内部をNGで記録。 | 現印刷のペグ/穴を測り、意図した差込/圧入と組立不能を深さ/方向で区別する。隠し座・公差・接着面の候補を左右で比較し、指の外形と到達長を保つ。<br>証拠: 全組合せ/全挿入の実形状検査、実ペグ穴/保持/接着記録、旧爪/指/飾りの再使用可否。Guardの原型問題はRV-10へ分離する。Gray/Blackの爪・指・指先は鏡像指定なしの同形複製で、現モデルの左右鏡像と回転/対称性で一致するか実物も確認する。 | なし | [AP-083](additional-purchases.md#ap-083) / [AP-094](additional-purchases.md#ap-094)；[腕](additional-printing.md#arm) / [未採用候補](additional-printing.md#candidates) / [既存3MFと印刷手順](additional-printing.md#plates) |

## 検証

- 同期前GitHubの107件の本文は見直し前planの描画結果と全件一致。保存されたコメント11件は過去監査/公開記録で、新しい在庫・実測の証拠は無い。Closed番号は81/82/83/84/93を確認。
- 107件の本文すべてと24タイトルを変更。固定監査リンクの脱落0。

- `plan._validate()`：107キー、個別本文107件、親/依存の参照、ラベル/マイルストーン、循環なし、Closed5件の固定、旧main本文リンクなし。
- `tools/tests/test_issue_sync.py`：9試験合格。状態保持、依存削除の対象限定、管理ラベル、dry-run、文書生成の冪等性を検証。
- 購入134品目から103品目・410参照を課題別に選び、購入/印刷の明示アンカーを含む現ブランチリンク1198件のローカル参照を確認（欠落0）。固定監査リンク46件の脱落0。GitHubの更新・状態・コメント保持は同期後の実測記録へ分ける。

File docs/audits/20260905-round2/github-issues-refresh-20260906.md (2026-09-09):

# GitHub Issue / Project 最新確認と追記案（2026-09-06）

**状態: `REVIEW_REQUIRED_APPEND_ONLY_NO_EXTERNAL_UPDATE`。** `gh` の読み取り再取得とローカル計画生成だけを行い、commit/push/Issue/Project外部更新は行っていない。各行は候補案で、最終freeze2根拠と最終commit/PRの代用ではない。

## 最新読み取り

- Issueは **107件（#3〜#109）**、OPEN **102件**、CLOSED **5件（#81/#82/#83/#84/#93）**。Closedは再openしない。
- Project #2「Tachikoma 物理製作」は現在 **96項目**。Status読戻しは Blocked 55 / Done 5 / In Progress 13 / Ready 15 / Todo 8。#99〜#109の11件は未掲載。
- 現在のProject掲載項目の正式依存173辺（公開後履歴156辺）を保持。新規本文に含まれる関連番号14件は候補として記録し、正式依存辺へは追加していない。
- 今回の読み取りはメタデータだけを再取得した。Issue本文・トークン・外部記録は候補記録へ保存していない。

## 全107件の個別追記案

JSONの `all_issue_append_only_update_plan` に #3〜#109 の107行を保存し、各行へ固有の `acceptance_condition`、`acceptance_next_step`、`acceptance_evidence_refs`、候補証拠束の状態を付けた。受入条件は **107件すべて固有**で、共通定型文だけの追記案ではない。

外部反映時は、既存Issueの本文・タイトル・状態・担当・コメント・ラベルを保持し、各行の受入条件に沿った一度の追記だけを行う。#99〜#109は個別に追加し、Project #2へ全107件を掲載して各Status・分類・依存をreadbackする。

外部追記の共通前提はJSONの `final_update_template` に未記入欄として保存した。最終commit SHA、draft PR URL、最終freeze2台帳SHA、根拠索引SHAが揃うまで、107行の候補文をそのままコメントへ使用しない。

## 印刷優先設計の候補証拠

- 現行assemblyからの設計必要数は **56**、初回試作内数 **31**、残り **25**。条件付き新規脛殻4を含む最大は **60**。既存脛殻4の局所加工と新規4は択一で、LD治具3種は本番へ加算しない。
- 印刷解放はA/B/Cに分ける。Aは初回全体仮組み31個（全体仮組み用body16＋左右/前後の固有脚部品10＋1脚分足裏5（TPU靴1＋スペーサー4））で、その内側の実物適合の最小対象が1靴・1脚。BはAの合格後に進める残り25個、Cは既存脛殻4個の局所加工・再使用が不成立の場合だけ選ぶ新規4個（完成機最大60個）です。A＋B=56個で設計必要数56個に一致し、CはA/Bへ加えません。`currently_printable_quantity=0` は現時点の解放未確定を示し、追加印刷全体を不要とする値ではありません。
- `print-first-manifest.json` は `FREEZE2_PENDING_CANDIDATE`、orientationは標準cap **X+90**・鏡像cap **X-90**、実形状の皿頭側上の局所確認を記録している。XIAO候補は基板占有/床/リブ/holder unionだけ+Z4、camera child/lensは固定、FPCのカメラ端固定・基板端+Z4・余長9.2mmを記録している。
- 候補証拠束は `candidate_evidence_bundle` にファイルSHA付きで保存した。最終freeze2根拠が揃うまで、印刷可数0・実在庫・実印刷・実機合格とは区別する。外部追記に必要な最終commit/PR/根拠索引はJSONの `final_update_template` に置いた未記入欄へ記録する。

## 公開境界と実行順

- `outputs/` は再帰追加せず、最終freeze2後にallowlistが個別選択した小さい根拠だけを対象にする。衝突計算キャッシュ、実行形式・ビルド生成物、一時再現束、重複URDF mesh、製造元の原本STEP/STL、絶対パス、外部記録の個人情報は候補から除外する。
- 公開前に最終freeze2成果からallowlist・台帳・説明文を再生成し、`gh auth status`、最新Issue全107件、Project全107件、依存辺、staged file list、秘密/絶対パスをreadbackする。
- root最終レビュー後の順序は normal push → draft PR → 各Issueの個別追記 → Project #2への不足11件追加 → 全107件readback。現時点の外部更新は0件。

詳細JSON: [`github-issues-refresh-20260906.json`](github-issues-refresh-20260906.json)。

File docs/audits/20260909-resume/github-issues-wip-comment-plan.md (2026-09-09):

# GitHub 107件 WIP追記案（2026-09-09）

この文書と同名JSONは、Issue #3〜#109の107件へ将来追記するコメントの作業案です。JSONの`issue_rows`には107件すべての個別`comment_draft`を収録しています。外部投稿は行っていません。

GitHub内のURLは暫定的に [`codex/print-first-20260905`](https://github.com/hapx2yuki/Tachikoma/tree/codex/print-first-20260905) を指します。公開直前に実際の公開commitへ置き換えます。

## 現在地

- 監査対象はIssue #3〜#109の107件。ライブ状態はOPEN 102件、CLOSED 5件、Project #2は96件、正式な依存辺は156本です。これは投稿準備の読み取り結果で、外部への書き込みはしていません。
- 生成・validate-onlyは終了コード0ですが、実機完成を示しません。source 236件と履歴3MF 26件のSHA一致、86部品／23リンク／視覚STL 56件／衝突STL 24件の記録があります。
- 最新Cabin formalは事前検査296件PASS、source 304件不変の後、battery通過後にMouth_Cannon_Greyの表面被覆0.815934…で`mj_step`前停止しています。
- 現行証跡には全1141 trace／20軸12区間とbody fullmesh `DYNAMIC_PASS`（固定動的交差0・error0）があります。別schemaの全linkpair／厳密な動的物理は未完了です。
- 近似診断は自己衝突OFFで26秒実行し転倒なしでしたが、後退4.557 mm/sは既存5 mm/s基準未満です。正式な動的合格には使いません。
- 追加購入方針0件、印刷候補56件（A31+B25）、C条件付き4件を維持します。現物在庫・不足は未確認です。
- 初期歩行候補ではCabin殻・装飾・peg・turretを保管し、`pf_cabin_rail_l/r`（電装支柱一体）・棚・`battery_cradle`・`pf_chassis`を維持します。ねじ・配線の露出は実物確認事項です。

## 共通コメント形式

107件の本文を、共通短文に続く箇条書きへ整形しました。従来計画に由来する個別受入条件は旧仕様として原文を残し、現行候補の採否条件と分けています。近似診断の細数値は、該当する#55/#78/#80/#96だけに追記しています。

```text
WIP監査記録（2026-09-09）。印刷優先構成と追加購入方針0件（現物在庫・不足は未確認）を確認中。実機・最終print-firstは未完了。以下はWIP整理であり、機構認定・量産許可・実機完成を示さない。公開監査README: https://github.com/hapx2yuki/Tachikoma/blob/codex/print-first-20260905/docs/audits/20260909-resume/README.md
- 現在確認: {issue_specific_focus}。
- 受入条件（従来計画。現構成への適用は以下参照）: {acceptance_condition}。
- 次作業: {acceptance_next_step}。
- 依存（ライブ）: 親 #x / blocked by #y。
- 計画との差分: 計画との差分なし。
- Project #2: In Progress / E7。
- 根拠: 指定された公開ファイルURL。
```

## 整形例

### #55

```text
WIP監査記録（2026-09-09）。印刷優先構成と追加購入方針0件（現物在庫・不足は未確認）を確認中。実機・最終print-firstは未完了。以下はWIP整理であり、機構認定・量産許可・実機完成を示さない。公開監査README: https://github.com/hapx2yuki/Tachikoma/blob/codex/print-first-20260905/docs/audits/20260909-resume/README.md
- 現在確認: 設計課題「H-06 [CAD] Cabin内部の電装室・基板保持・挿入経路・配線を成立させる」: 実メッシュ/実測による成立条件を確認し、局所判定を全体完成へ読み替えない。
- 受入条件（従来計画。現構成への適用は以下参照）: 全体干渉・基板挿入/脱着・保持/熱/通線の検査と候補採否。変更質量/重心をI-08、印刷影響をP-05へ渡す。
- 次作業: 購入基板・USB/電源端子を実測し、RV-15と境界寸法を共有して部品配置/棚/保守経路を修正する。ESP32/PCA/電源を収め、短FPCのXIAOはH-02の頭内保持へ残す。
- 固有監査: 最新Cabin formalは事前検査296件PASS、source304件不変、battery通過後にMouth_Cannon_Greyが16007/19618＝0.815934...でmj_step前停止した。
- 現行診断補足: 全1141 trace／20軸12区間と body fullmesh `DYNAMIC_PASS`（固定動的交差0・error0）を保存済み。別schemaの全linkpair／厳密な動的物理は未完了。26秒の自己衝突OFF近似は転倒なしだが、後退4.557 mm/s < 既存5 mm/sで移動量ゲート不合格。
- 依存（ライブ）: 親 #8 / blocked by なし。
- 計画との差分: 計画との差分なし。
- Project #2: In Progress / E6 頭部。
- 根拠: https://github.com/hapx2yuki/Tachikoma/blob/codex/print-first-20260905/docs/audits/20260905-round2/cabin.md
```
### #90

```text
WIP監査記録（2026-09-09）。印刷優先構成と追加購入方針0件（現物在庫・不足は未確認）を確認中。実機・最終print-firstは未完了。以下はWIP整理であり、機構認定・量産許可・実機完成を示さない。公開監査README: https://github.com/hapx2yuki/Tachikoma/blob/codex/print-first-20260905/docs/audits/20260909-resume/README.md
- 現在確認: 設計課題「RV-09 [機構不具合] 頭部内の実サーボケースとポッド梁の干渉を解消する」: 実メッシュ/実測による成立条件を確認し、局所判定を全体完成へ読み替えない。
- 受入条件（従来計画。現構成への適用は以下参照）: 全ケース/眼/基板/梁の同時成立、壁厚/挿入/工具/配線の根拠と採否。固定軸をRV-13/14/10へ渡し有限失敗を不可能の証明と呼ばない。
- 現行受入確認: 実購入寸法を反映したケース・眼・基板・梁の実メッシュ干渉、印刷支持、工具／挿入、電装配線、取付強度を同一候補で確認する。
- 次作業: P-03/P-07の実購入寸法を照合し、印刷支持・目／カメラの電装配線・実メッシュ干渉・取付強度を同時に確認する。必要なら外観変更を候補に含める。
- 旧仕様の扱い: 「外観を保つ」「内部削りのみ」は旧完全意匠の履歴条件として保留し、現行採否へ使わない。
- 固有監査: 旧Head_Top_Eyecut対pod_neckの89.23001 mm3は旧構成の履歴値で、現行集合は旧pod_neckを収集しない。
- 依存（ライブ）: 親 #9 / blocked by なし。
- 計画との差分: 計画との差分なし。
- Project #2: In Progress / E7 意匠シェル。
- 根拠: https://github.com/hapx2yuki/Tachikoma/blob/codex/print-first-20260905/docs/audits/20260905-round2/simulation.md
```
### #96

```text
WIP監査記録（2026-09-09）。印刷優先構成と追加購入方針0件（現物在庫・不足は未確認）を確認中。実機・最終print-firstは未完了。以下はWIP整理であり、機構認定・量産許可・実機完成を示さない。公開監査README: https://github.com/hapx2yuki/Tachikoma/blob/codex/print-first-20260905/docs/audits/20260909-resume/README.md

- 現在確認: 設計課題「RV-15 [機構不具合] 首・Cabin・装飾を全長で組み合わせ、支持と挿入を成立させる」: 実メッシュ/実測による成立条件を確認し、局所判定を全体完成へ読み替えない。
- 受入条件（従来計画。現構成への適用は以下参照）: 首/Cabin/Eye/装飾/電装の全体交差と挿入・通線・保守・段階荷重の記録。既存11候補を採用済みとしない。
- 現行受入確認: Cabin殻・装飾・peg・turret保管後の pf_cabin_rail_l/r（電装支柱一体）・棚・battery_cradle・pf_chassisについて、支持・電装配線・実測着脱・全mesh干渉・段階荷重／印刷強度を確認する。
- 次作業: H-06について、現行頭支持座・シャーシ・棚の固定、配線経路、取り出しを実測し、保管後の支持部品・配線・全mesh・強度を同一候補で検証する。
- 旧仕様の扱い: 「外形を保つ内側加工」「首/Cabin/Eye/装飾/電装を全て組む」は旧完全意匠の履歴条件として保留し、現行採否へ使わない。
- 固有監査: 部品別診断は144件で51 PASS／87 FAIL／6 TIMEOUT。FAILは主にVHACD表面被覆・検証変換で、機体欠陥87件とは読まない。Cabin殻・装飾・peg・turretを保管し、pf_cabin_rail_l/rの一体電装支柱・棚・battery_cradle・pf_chassisを維持する方針である。
- 現行診断補足: 全1141 trace／20軸12区間と body fullmesh `DYNAMIC_PASS`（固定動的交差0・error0）を保存済み。別schemaの全linkpair／厳密な動的物理は未完了。26秒の自己衝突OFF近似は転倒なしだが、後退4.557 mm/s < 既存5 mm/sで移動量ゲート不合格。
- 依存（ライブ）: 親 #9 / blocked by なし。
- 計画との差分: 計画との差分なし。
- Project #2: In Progress / E7 意匠シェル。
- 根拠: https://github.com/hapx2yuki/Tachikoma/blob/codex/print-first-20260905/docs/audits/20260905-round2/neck-reinforcement.md
```

## #90/#96の旧前提の扱い

- #90の「外観を保つ」「内部削りのみ」は、旧完全意匠の履歴条件としてコメントに残し、現行採否から外しました。現行は印刷支持、電装配線、実メッシュ干渉、実測、取付強度を確認します。
- #96の「外形を保つ内側加工」「首/Cabin/Eye/装飾/電装を全て組む」も旧完全意匠の履歴条件として保留しました。現行はCabin殻・装飾・peg・turretを保管し、電装支柱一体の`pf_cabin_rail_l/r`、棚、`battery_cradle`、`pf_chassis`の支持・配線・着脱・全mesh・強度を確認します。
- `source_plan`の受入条件と、現行印刷支持・電装配線・実測・全mesh・強度による判定は、JSONの`acceptance_semantics`でも区別しています。

## 個別の監査値

| Issue | 追記する固有情報 |
|---:|---|
| #12 / #15 / #27 | 追加購入方針0件、印刷候補56件（A31+B25）、C条件付き4件。必要数と現物不足は未確認。 |
| #55 | Cabin formalの停止値と、全trace/body fullmeshの現行診断補足。 |
| #78 / #80 | 部品別診断144件の集計、全trace/body fullmesh、自己衝突OFF近似の位置づけ。 |
| #96 | 部品別診断、Cabin保管後の現行支持構成、全trace/body fullmesh、旧仕様の履歴保留。 |
| #90 | 旧Head_Top_Eyecut対pod_neckの値を履歴として保持し、現行の支持・配線・実測・全mesh・強度へ切り替え。 |
| #62 / #82 | 現行頭候補の根拠と履歴3MFのSHA記録。 |

## 依存と公開順序

JSONの各`formal_dependency`にあるライブ親・ライブblocked byを本文へ転記しました。計画にだけ残る依存は「計画との差分」に明記し、ライブの依存関係へ先回りして追加していません。Project #2の未掲載行は公開順序で追加予定と表示します。

投稿順序は、まず監査READMEを実commitへ置いた後、JSONの`publication_order`に従います。URLのブランチ置換と外部投稿は、この作業案の範囲外です。

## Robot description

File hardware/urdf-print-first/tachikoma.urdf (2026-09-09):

<?xml version="1.0" ?>
<robot name="tachikoma">
  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
  <link name="base_link">
    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
    <inertial>
      <origin xyz="0.000449752 -0.024353633 0.043612638" rpy="0 0 0"/>
      <mass value="1.153146443"/>
      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
    </inertial>
  </link>
  <link name="leg_fr_coxa">
    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
    <inertial>
      <origin xyz="0.013028243 0.007420538 0.002289949" rpy="0 0 0"/>
      <mass value="0.112432718"/>
      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
    </inertial>
  </link>
  <link name="leg_fr_femur">
    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
    <inertial>
      <origin xyz="0.052740806 0.005721771 -0.000000000" rpy="0 0 0"/>
      <mass value="0.109741392"/>
      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
    </inertial>
  </link>
  <link name="leg_fr_tibia">
    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
    <inertial>
      <origin xyz="0.003379225 -0.002105299 -0.087007607" rpy="0 0 0"/>
      <mass value="0.114256289"/>
      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
    </inertial>
  </link>
  <link name="leg_fl_coxa">
    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
    <inertial>
      <origin xyz="0.013028244 -0.007420539 0.002289948" rpy="0 0 0"/>
      <mass value="0.112432710"/>
      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
    </inertial>
  </link>
  <link name="leg_fl_femur">
    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
    <inertial>
      <origin xyz="0.052740806 -0.005721771 -0.000000000" rpy="0 0 0"/>
      <mass value="0.109741392"/>
      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
    </inertial>
  </link>
  <link name="leg_fl_tibia">
    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
    <inertial>
      <origin xyz="0.003379245 0.001903319 -0.087007654" rpy="0 0 0"/>
      <mass value="0.114256454"/>
      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
    </inertial>
  </link>
  <link name="leg_rl_coxa">
    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
    <inertial>
      <origin xyz="0.013028243 0.007420538 0.002289949" rpy="0 0 0"/>
      <mass value="0.112432718"/>
      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
    </inertial>
  </link>
  <link name="leg_rl_femur">
    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
    <inertial>
      <origin xyz="0.052740806 0.005721771 -0.000000000" rpy="0 0 0"/>
      <mass value="0.109741392"/>
      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
    </inertial>
  </link>
  <link name="leg_rl_tibia">
    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
    <inertial>
      <origin xyz="0.003379225 -0.002105299 -0.087007607" rpy="0 0 0"/>
      <mass value="0.114256289"/>
      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
    </inertial>
  </link>
  <link name="leg_rr_coxa">
    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
    <inertial>
      <origin xyz="0.013028244 -0.007420539 0.002289948" rpy="0 0 0"/>
      <mass value="0.112432710"/>
      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
    </inertial>
  </link>
  <link name="leg_rr_femur">
    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
    <inertial>
      <origin xyz="0.052740806 -0.005721771 -0.000000000" rpy="0 0 0"/>
      <mass value="0.109741392"/>
      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
    </inertial>
  </link>
  <link name="leg_rr_tibia">
    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
    <inertial>
      <origin xyz="0.003379245 0.001903319 -0.087007654" rpy="0 0 0"/>
      <mass value="0.114256454"/>
      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
    </inertial>
  </link>
  <link name="arm_r_shoulder">
    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
    <inertial>
      <origin xyz="0.012620364 -0.004259118 -0.014288842" rpy="0 0 0"/>
      <mass value="0.023542634"/>
      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
    </inertial>
  </link>
  <link name="arm_r_upper">
    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
    <inertial>
      <origin xyz="0.039545225 -0.002827195 0.000491075" rpy="0 0 0"/>
      <mass value="0.036127779"/>
      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
    </inertial>
  </link>
  <link name="arm_r_forearm">
    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
    <inertial>
      <origin xyz="0.019268348 0.002138717 0.000213429" rpy="0 0 0"/>
      <mass value="0.008867549"/>
      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
    </inertial>
  </link>
  <link name="arm_l_shoulder">
    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
    <inertial>
      <origin xyz="-0.012620364 -0.004259118 -0.014288842" rpy="0 0 0"/>
      <mass value="0.023542634"/>
      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
    </inertial>
  </link>
  <link name="arm_l_upper">
    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
    <inertial>
      <origin xyz="-0.039545225 -0.002827195 0.000491075" rpy="0 0 0"/>
      <mass value="0.036127779"/>
      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
    </inertial>
  </link>
  <link name="arm_l_forearm">
    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
    <inertial>
      <origin xyz="-0.019268351 0.002138716 0.000213432" rpy="0 0 0"/>
      <mass value="0.008867551"/>
      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
    </inertial>
  </link>
  <link name="eye_r_pod">
    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
    <inertial>
      <origin xyz="-0.000036726 0.000024812 0.011415847" rpy="0 0 0"/>
      <mass value="0.007552717"/>
      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
    </inertial>
  </link>
  <link name="eye_l_pod">
    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
    <inertial>
      <origin xyz="-0.000036726 0.000024812 0.011415847" rpy="0 0 0"/>
      <mass value="0.007552717"/>
      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
    </inertial>
  </link>
  <link name="eye_pod_camera">
    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
    <inertial>
      <origin xyz="-0.000000478 -0.000930441 0.005632732" rpy="0 0 0"/>
      <mass value="0.030306603"/>
      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
    </inertial>
  </link>
  <link name="camera_optical_frame">
    <inertial>
      <origin xyz="0.000000000 0.000000000 0.000000000" rpy="0 0 0"/>
      <mass value="0.001000000"/>
      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
    </inertial>
  </link>
  <joint name="leg_fr_yaw" type="revolute">
    <parent link="base_link"/>
    <child link="leg_fr_coxa"/>
    <origin xyz="0.082103695 0.021999619 0.000000000" rpy="0.000000000 0.000000000 0.261799388"/>
    <axis xyz="0.000000 0.000000 1.000000"/>
    <limit lower="-0.698132" upper="0.698132" effort="1.955881861111111" velocity="7.033416388633864"/>
  </joint>
  <joint name="leg_fr_pitch" type="revolute">
    <parent link="leg_fr_coxa"/>
    <child link="leg_fr_femur"/>
    <origin xyz="0.026000000 0.000000000 0.000000000" rpy="0.000000000 0.000000000 0.000000000"/>
    <axis xyz="0.000000 1.000000 0.000000"/>
    <limit lower="-0.785398" upper="0.959931" effort="1.955881861111111" velocity="7.033416388633864"/>
  </joint>
  <joint name="leg_fr_knee" type="revolute">
    <parent link="leg_fr_femur"/>
    <child link="leg_fr_tibia"/>
    <origin xyz="0.070000000 0.000000000 0.000000000" rpy="0.000000000 0.000000000 0.000000000"/>
    <axis xyz="0.000000 1.000000 0.000000"/>
    <limit lower="-0.767945" upper="0.767945" effort="1.955881861111111" velocity="7.033416388633864"/>
  </joint>
  <joint name="leg_fl_yaw" type="revolute">
    <parent link="base_link"/>
    <child link="leg_fl_coxa"/>
    <origin xyz="-0.082103695 0.021999619 0.000000000" rpy="0.000000000 0.000000000 2.879793266"/>
    <axis xyz="0.000000 0.000000 1.000000"/>
    <limit lower="-0.698132" upper="0.698132" effort="1.955881861111111" velocity="7.033416388633864"/>
  </joint>
  <joint name="leg_fl_pitch" type="revolute">
    <parent link="leg_fl_coxa"/>
    <child link="leg_fl_femur"/>
    <origin xyz="0.026000000 0.000000000 0.000000000" rpy="0.000000000 0.000000000 0.000000000"/>
    <axis xyz="-0.000000 1.000000 0.000000"/>
    <limit lower="-0.785398" upper="0.959931" effort="1.955881861111111" velocity="7.033416388633864"/>
  </joint>
  <joint name="leg_fl_knee" type="revolute">
    <parent link="leg_fl_femur"/>
    <child link="leg_fl_tibia"/>
    <origin xyz="0.070000000 0.000000000 0.000000000" rpy="0.000000000 0.000000000 0.000000000"/>
    <axis xyz="-0.000000 1.000000 0.000000"/>
    <limit lower="-0.767945" upper="0.767945" effort="1.955881861111111" velocity="7.033416388633864"/>
  </joint>
  <joint name="leg_rl_yaw" type="revolute">
    <parent link="base_link"/>
    <child link="leg_rl_coxa"/>
    <origin xyz="-0.073612159 -0.042500000 0.000000000" rpy="0.000000000 0.000000000 -2.617993878"/>
    <axis xyz="0.000000 0.000000 1.000000"/>
    <limit lower="-0.698132" upper="0.698132" effort="1.955881861111111" velocity="7.033416388633864"/>
  </joint>
  <joint name="leg_rl_pitch" type="revolute">
    <parent link="leg_rl_coxa"/>
    <child link="leg_rl_femur"/>
    <origin xyz="0.026000000 -0.000000000 0.000000000" rpy="0.000000000 0.000000000 -0.000000000"/>
    <axis xyz="0.000000 1.000000 0.000000"/>
    <limit lower="-0.785398" upper="0.959931" effort="1.955881861111111" velocity="7.033416388633864"/>
  </joint>
  <joint name="leg_rl_knee" type="revolute">
    <parent link="leg_rl_femur"/>
    <child link="leg_rl_tibia"/>
    <origin xyz="0.070000000 0.000000000 0.000000000" rpy="0.000000000 0.000000000 -0.000000000"/>
    <axis xyz="0.000000 1.000000 0.000000"/>
    <limit lower="-0.767945" upper="0.767945" effort="1.955881861111111" velocity="7.033416388633864"/>
  </joint>
  <joint name="leg_rr_yaw" type="revolute">
    <parent link="base_link"/>
    <child link="leg_rr_coxa"/>
    <origin xyz="0.073612159 -0.042500000 0.000000000" rpy="0.000000000 0.000000000 -0.523598776"/>
    <axis xyz="0.000000 0.000000 1.000000"/>
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

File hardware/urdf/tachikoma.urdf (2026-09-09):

<?xml version="1.0" ?>
<robot name="tachikoma">
  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
  <link name="base_link">
    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
    <inertial>
      <origin xyz="0.000032780 -0.076496491 0.047800635" rpy="0 0 0"/>
      <mass value="1.466825865"/>
      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
    </inertial>
  </link>
  <link name="leg_fr_coxa">
    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
    <inertial>
      <origin xyz="0.016059702 0.006263254 0.001080865" rpy="0 0 0"/>
      <mass value="0.083787095"/>
      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
    </inertial>
  </link>
  <link name="leg_fr_femur">
    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
    <inertial>
      <origin xyz="0.052117246 0.003560833 0.001704550" rpy="0 0 0"/>
      <mass value="0.095788395"/>
      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
    </inertial>
  </link>
  <link name="leg_fr_tibia">
    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
    <inertial>
      <origin xyz="0.004813252 -0.001704383 -0.079532817" rpy="0 0 0"/>
      <mass value="0.094299363"/>
      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
    </inertial>
  </link>
  <link name="leg_fl_coxa">
    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
    <inertial>
      <origin xyz="0.016059702 -0.006263254 0.001080865" rpy="0 0 0"/>
      <mass value="0.083787095"/>
      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
    </inertial>
  </link>
  <link name="leg_fl_femur">
    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
    <inertial>
      <origin xyz="0.052117246 -0.003570510 0.001704550" rpy="0 0 0"/>
      <mass value="0.095788395"/>
      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
    </inertial>
  </link>
  <link name="leg_fl_tibia">
    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
    <inertial>
      <origin xyz="0.004813252 0.002528501 -0.079532817" rpy="0 0 0"/>
      <mass value="0.094299363"/>
      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
    </inertial>
  </link>
  <link name="leg_rl_coxa">
    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
    <inertial>
      <origin xyz="0.016059702 0.006263254 0.001080865" rpy="0 0 0"/>
      <mass value="0.083787095"/>
      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
    </inertial>
  </link>
  <link name="leg_rl_femur">
    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
    <inertial>
      <origin xyz="0.052117246 0.003560833 0.001704550" rpy="0 0 0"/>
      <mass value="0.095788395"/>
      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
    </inertial>
  </link>
  <link name="leg_rl_tibia">
    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
    <inertial>
      <origin xyz="0.004813252 -0.001704383 -0.079532817" rpy="0 0 0"/>
      <mass value="0.094299363"/>
      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
    </inertial>
  </link>
  <link name="leg_rr_coxa">
    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
    <inertial>
      <origin xyz="0.016059702 -0.006263254 0.001080865" rpy="0 0 0"/>
      <mass value="0.083787095"/>
      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
    </inertial>
  </link>
  <link name="leg_rr_femur">
    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
    <inertial>
      <origin xyz="0.052117246 -0.003570510 0.001704550" rpy="0 0 0"/>
      <mass value="0.095788395"/>
      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
    </inertial>
  </link>
  <link name="leg_rr_tibia">
    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
    <inertial>
      <origin xyz="0.004813252 0.002528501 -0.079532817" rpy="0 0 0"/>
      <mass value="0.094299363"/>
      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
    </inertial>
  </link>
  <link name="arm_r_shoulder">
    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
    <inertial>
      <origin xyz="0.012620364 -0.004259118 -0.014288842" rpy="0 0 0"/>
      <mass value="0.023542634"/>
      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
    </inertial>
  </link>
  <link name="arm_r_upper">
    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
    <inertial>
      <origin xyz="0.039121158 -0.002799232 0.000662638" rpy="0 0 0"/>
      <mass value="0.036488674"/>
      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
    </inertial>
  </link>
  <link name="arm_r_forearm">
    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
    <inertial>
      <origin xyz="0.019166790 0.002228285 0.000228135" rpy="0 0 0"/>
      <mass value="0.008528994"/>
      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
    </inertial>
  </link>
  <link name="arm_l_shoulder">
    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
    <inertial>
      <origin xyz="-0.012620364 -0.004259118 -0.014288842" rpy="0 0 0"/>
      <mass value="0.023542634"/>
      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
    </inertial>
  </link>
  <link name="arm_l_upper">
    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
    <inertial>
      <origin xyz="-0.039121158 -0.002799232 0.000662638" rpy="0 0 0"/>
      <mass value="0.036488674"/>
      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
    </inertial>
  </link>
  <link name="arm_l_forearm">
    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
    <inertial>
      <origin xyz="-0.019166790 0.002228285 0.000228135" rpy="0 0 0"/>
      <mass value="0.008528994"/>
      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
    </inertial>
  </link>
  <link name="eye_r_pod">
    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
    <inertial>
      <origin xyz="-0.000036726 0.000024812 0.011415847" rpy="0 0 0"/>
      <mass value="0.007552717"/>
      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
    </inertial>
  </link>
  <link name="eye_l_pod">
    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
    <inertial>
      <origin xyz="-0.000036726 0.000024812 0.011415847" rpy="0 0 0"/>
      <mass value="0.007552717"/>
      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
    </inertial>
  </link>
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

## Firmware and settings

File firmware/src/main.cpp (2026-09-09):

// タチコマ歩行ロボット ファームウェア
// ESP32 + PCA9685 + 12サーボ (3DOF x 4脚) + WS2812 + DFPlayer
// 操作: WiFi AP "Tachikoma" に接続し http://192.168.4.1/

#include <Arduino.h>
#include <ArduinoJson.h>
#include <ESPAsyncWebServer.h>
#include <ESPmDNS.h>
#include <Preferences.h>
#include <WiFi.h>
#include <Wire.h>
#include <esp_task_wdt.h>

#include "arms.h"
#include "audio.h"
#include "config.h"
#include "control.h"
#include "eyes.h"
#include "gait.h"
#include "leg_output.h"
#include "peripherals.h"
#include "servos.h"
#include "web_ui.h"

Servos servos;
Gait gait;
Arms arms;
Eyes eyes;
Peripherals peri;
Audio audio;
AsyncWebServer server(80);
AsyncWebSocket ws("/ws");      // 操作系 (移動/腕/目/PTT)
AsyncWebSocket wsAudio("/audio");  // 音声系 (ブリッジがクライアントとして接続)

// AsyncTCP (core0) は指令だけ更新し、運動状態は loop (core1) だけが変更する。
// volatile / 構造体代入だけでは複数フィールドの同時更新にはならない。
ControlState pendingControl;
uint32_t controlClientId = 0;
portMUX_TYPE controlMux = portMUX_INITIALIZER_UNLOCKED;
#ifdef CALIBRATION_MODE
volatile int cal_us = 1500;
volatile int cal_ch = -1;
#endif

// STA (iPhone テザリング) 資格情報は NVS 保存 (setupWiFi() と /wifi POST
// ハンドラ参照)。ハードコード禁止 — SSID/パスワードは Web UI の設定タブから入力する
String staSsid;
bool wifiApReady = false;
bool wifiStaConfigured = false;
String wifiStaState = "UNCONFIGURED";

bool isPlaceholderCredential(const String& value) {
  const char* candidates[] = {
      "change-me-8chars", "change-me", "password", "password123",
      "your-password", "your_password", "YOUR_PASSWORD"};
  for (const char* candidate : candidates)
    if (value == candidate) return true;
  return false;
}

bool validWifiCredentials(const String& ssid, const String& pass) {
  return ssid.length() >= 1 && ssid.length() <= 32 && pass.length() >= 8 &&
         pass.length() <= 63 && !isPlaceholderCredential(ssid) &&
         !isPlaceholderCredential(pass);
}

void refreshWifiState() {
  if (!wifiStaConfigured) return;
  switch (WiFi.status()) {
    case WL_CONNECTED: wifiStaState = "CONNECTED"; break;
    case WL_NO_SSID_AVAIL: wifiStaState = "SSID_NOT_FOUND"; break;
    case WL_CONNECT_FAILED: wifiStaState = "CONNECT_FAILED"; break;
    case WL_CONNECTION_LOST: wifiStaState = "CONNECTION_LOST"; break;
    case WL_DISCONNECTED: wifiStaState = "DISCONNECTED"; break;
    default: wifiStaState = "CONNECTING"; break;
  }
}

int servoCommandStatus() {
  if (servos.faulted() || !servos.i2cOk(0) || !servos.i2cOk(1) ||
      !peri.vbatVerified() || !servos.powerReady())
    return 503;
  if (!servos.ready()) return 409;
  return 200;
}

// HTTP は WebSocket の連続制御と同じ所有権を持たせる。active な WS が
// ある間は別クライアントの一発操作を拒否し、所有者がいないときだけ
// confirm=1 という明示操作を要求する。これは暗号認証ではなく、ローカル
// AP 上の誤クリック・別タブ競合を防ぐための安全確認である。
bool httpMutationConfirmed(AsyncWebServerRequest* r) {
  if (r->hasParam("confirm") && r->getParam("confirm")->value() == "1") return true;
  return r->hasParam("confirm", true) &&
         r->getParam("confirm", true)->value() == "1";
}

bool httpOwnerSessionMatches(AsyncWebServerRequest* r, uint32_t ownerId) {
  for (const bool post : {false, true}) {
    if (!r->hasParam("session", post)) continue;
    int session = 0;
    if (parseControlInteger(r->getParam("session", post)->value().c_str(),
                             1, 2147483647, session) &&
        static_cast<uint32_t>(session) == ownerId)
      return true;
  }
  return false;
}

bool httpMutationAllowed(AsyncWebServerRequest* r) {
  uint32_t activeOwnerId = 0;
  portENTER_CRITICAL(&controlMux);
  if (controlClientId != 0) {
    if (millis() - pendingControl.lastCmdMs <= CONTROL_LEASE_MS) {
      activeOwnerId = controlClientId;
    } else {
      // loop がまだ期限切れ処理をしていない場合も、HTTP 側で古い所有権を
      // 生かさない。速度/PTT/stand は次の loop で停止処理を通る。
      pendingControl.vx = pendingControl.vy = pendingControl.wz = 0;
      pendingControl.ptt = false;
      pendingControl.stand = false;
      controlClientId = 0;
    }
  }
  portEXIT_CRITICAL(&controlMux);
  if (activeOwnerId != 0) {
    // UI は WS_EVT_CONNECT で受け取った一時 session を返す。同じ制御
    // クライアントだけを通し、別タブ/別端末の HTTP は confirm を付けても拒否する。
    if (httpOwnerSessionMatches(r, activeOwnerId)) return true;
    r->send(409, "text/plain", "control is owned by an active WebSocket client");
    return false;
  }
  if (!httpMutationConfirmed(r)) {
    r->send(409, "text/plain", "confirm=1 required when no WebSocket owner is active");
    return false;
  }
  return true;
}

// 搭載設定を操作画面へ返し、未搭載の機能を成功表示で隠さない。
void addFeatureTelemetry(JsonDocument& doc) {
  doc["profile"] = HARDWARE_PROFILE;
  doc["features"]["status_leds"] = STATUS_LEDS_ENABLED;
  doc["features"]["dfplayer"] = DFPLAYER_ENABLED;
  doc["features"]["i2s_audio"] = audio.ready();
  doc["features"]["i2s_state"] = audio.stateName();
  doc["features"]["audio_volume_percent"] = TACHIKOMA_AUDIO_VOLUME_PERCENT;
  doc["features"]["body_h_min_mm"] = TK_CONTROL_BODY_H_MIN;
  doc["features"]["body_h_max_mm"] = TK_CONTROL_BODY_H_MAX;
  doc["features"]["body_h_default_mm"] = TK_CONTROL_BODY_H_DEFAULT;
  doc["features"]["print_first_profile"] = PRINT_FIRST_PROFILE_ENABLED;
#if TACHIKOMA_PRINT_FIRST_PROFILE
  doc["features"]["print_first_profile_status"] = PRINT_FIRST_PROFILE_STATUS;
  doc["features"]["print_first_profile_adopted"] = PRINT_FIRST_PROFILE_ADOPTED;
#else
  doc["features"]["print_first_profile_status"] = "INACTIVE";
  doc["features"]["print_first_profile_adopted"] = false;
#endif
}

void onWsEvent(AsyncWebSocket*, AsyncWebSocketClient* client, AwsEventType type,
               void* arg, uint8_t* data, size_t len) {
  if (type == WS_EVT_CONNECT) {
    if (client) {
      String session = "{\"type\":\"control_session\",\"session\":";
      session += static_cast<int>(client->id());
      session += "}";
      client->text(session.c_str());
    }
    return;
  }
  if (type == WS_EVT_DISCONNECT) {
    portENTER_CRITICAL(&controlMux);
    if (client && client->id() == controlClientId) {
      pendingControl.vx = pendingControl.vy = pendingControl.wz = 0;
      pendingControl.ptt = false;
      pendingControl.stand = false;
      controlClientId = 0;
    }
    portEXIT_CRITICAL(&controlMux);
    return;
  }
  if (type != WS_EVT_DATA) return;
  // 分割フレームは扱わない (UI の送信サイズなら単一フレームで収まる)
  AwsFrameInfo* info = (AwsFrameInfo*)arg;
  if (!info->final || info->index != 0 || info->len != len ||
      info->opcode != WS_TEXT) return;
  if (len > 512) return;  // UI の指令は数十バイト。異常フレームは捨てる (F-09)
  JsonDocument doc;
  if (deserializeJson(doc, data, len)) return;
  const bool heartbeat = !doc["vx"].isNull() && !doc["vy"].isNull() &&
                         !doc["wz"].isNull();
  portENTER_CRITICAL(&controlMux);
  const bool owner = client && (controlClientId == 0 || client->id() == controlClientId);
  if (!owner) {
    portEXIT_CRITICAL(&controlMux);
    if (client) client->text("{\"type\":\"control_busy\"}");
    return;
  }
  if (updateControlFromJson(doc, pendingControl, millis()) && client && heartbeat &&
      controlClientId == 0)
    controlClientId = client->id();
  portEXIT_CRITICAL(&controlMux);
}

void onAudioWsEvent(AsyncWebSocket* s, AsyncWebSocketClient* c, AwsEventType type,
                     void* arg, uint8_t* data, size_t len) {
  audio.onEvent(s, c, type, arg, data, len);
}

// AP は常時維持 (操作UIのフォールバック)。STA は NVS 保存の資格情報が
// あれば iPhone テザリングへ join を試みる (資格情報はソースに置かない)
void setupWiFi() {
  WiFi.mode(WIFI_AP_STA);
  WiFi.setAutoReconnect(true);  // テザリング切断後の STA 再接続 (F-10)
  const String apSsid(AP_SSID), apPass(AP_PASS);
  if (validWifiCredentials(apSsid, apPass)) {
    wifiApReady = WiFi.softAP(AP_SSID, AP_PASS);
    if (!wifiApReady) wifiStaState = "AP_FAILED";
  } else {
    wifiApReady = false;
    wifiStaState = "AP_UNCONFIGURED";
  }

  Preferences p;
  p.begin(STA_PREFS_NS, /*readOnly=*/true);
  staSsid = p.getString("ssid", "");
  const String staPass = p.getString("pass", "");
  p.end();
  if (validWifiCredentials(staSsid, staPass)) {
    wifiStaConfigured = true;
    wifiStaState = "CONNECTING";
    WiFi.begin(staSsid.c_str(), staPass.c_str());
  } else {
    wifiStaConfigured = false;
    if (staSsid.length()) wifiStaState = "STA_CREDENTIALS_INVALID";
  }

  if (MDNS.begin(MDNS_HOST)) MDNS.addService("http", "tcp", 80);
}

void setupWeb() {
  ws.onEvent(onWsEvent);
  server.addHandler(&ws);
  wsAudio.onEvent(onAudioWsEvent);
  server.addHandler(&wsAudio);
  server.on("/", HTTP_GET, [](AsyncWebServerRequest* r) {
    r->send(200, "text/html", (const __FlashStringHelper*)INDEX_HTML);
  });
  server.on("/play", HTTP_GET, [](AsyncWebServerRequest* r) {
    if (!r->hasParam("n")) {
      r->send(400, "text/plain", "track number required");
      return;
    }
    int track = 0;
    if (!parseControlInteger(r->getParam("n")->value().c_str(),
                             1, DFPLAYER_TRACK_MAX, track)) {
      r->send(400, "text/plain", "track number must be an integer in 1..9999");
      return;
    }
    if (!DFPLAYER_ENABLED) {
      r->send(409, "text/plain", "DFPlayer is not fitted in this profile; I2S voice remains available");
      return;
    }
    if (!httpMutationAllowed(r)) return;
    // DFPlayer の API は SD ファイルの存在を ACK しないため、200 は
    // 数値範囲内のキュー投入を意味し、mp3/NNNN.mp3 の存在は保証しない。
    if (!peri.queueTrack(track)) {
      r->send(503, "text/plain", "DFPlayer unavailable or track queue failed");
    } else {
      r->send(200, "text/plain", "ok");
    }
  });
  server.on("/eye", HTTP_GET, [](AsyncWebServerRequest* r) {
    // 視線モード: /eye?mode=kyoro|front|scan
    const String m = r->hasParam("mode") ? r->getParam("mode")->value() : "";
    int mode = -1;
    if (m == "kyoro") mode = Eyes::KYORO;
    else if (m == "front") mode = Eyes::FRONT;
    else if (m == "scan") mode = Eyes::SCAN;
    if (mode < 0) { r->send(400, "text/plain", "mode must be kyoro, front, or scan"); return; }
    if (!httpMutationAllowed(r)) return;
    const int status = servoCommandStatus();
    if (status != 200) {
      r->send(status, "text/plain", status == 409 ? "servo is at rest; explicit start required"
                                                    : "servo power or PCA is unavailable");
      return;
    }
    portENTER_CRITICAL(&controlMux);
    pendingControl.eyeMode = mode;
    portEXIT_CRITICAL(&controlMux);
    r->send(200, "text/plain", "ok");
  });
  server.on("/arm", HTTP_GET, [](AsyncWebServerRequest* r) {
    // プリセット: /arm?pose=tuck|ready|reach|wave
    const String p = r->hasParam("pose") ? r->getParam("pose")->value() : "";
    const float* pose = p == "tuck" ? ARM_POSE_TUCK :
                        p == "ready" ? ARM_POSE_READY :
                        p == "reach" ? ARM_POSE_REACH : nullptr;
    if (!pose && p != "wave") { r->send(400, "text/plain", "pose must be tuck, ready, reach, or wave"); return; }
    if (!httpMutationAllowed(r)) return;
    const int status = servoCommandStatus();
    if (status != 200) {
      r->send(status, "text/plain", status == 409 ? "servo is at rest; explicit start required"
                                                    : "servo power or PCA is unavailable");
      return;
    }
    portENTER_CRITICAL(&controlMux);
    if (pose) {
      pendingControl.arm.yaw = pose[0]; pendingControl.arm.pitch = pose[1];
      pendingControl.arm.elbow = pose[2]; pendingControl.armAction = 1;
    } else if (p == "wave") pendingControl.armAction = 2;
    portEXIT_CRITICAL(&controlMux);
    r->send(200, "text/plain", "ok");
  });
#ifdef CALIBRATION_MODE
  // 単体診断専用: /cal?ch=<使用中ch>&us=<軸別保護範囲内>。全軸同時に
  // パルスを出さず、選択した1軸以外は常時 full-off にする。
  server.on("/cal", HTTP_GET, [](AsyncWebServerRequest* r) {
    if (r->hasParam("stop") && r->getParam("stop")->value() == "1") {
      servos.stopCalibration();
      cal_ch = -1;
      r->send(200, "text/plain", "stopped");
      return;
    }
    if (!r->hasParam("ch") || !r->hasParam("us")) {
      r->send(400, "text/plain", "ch and us are required; one axis only");
      return;
    }
    if (servos.faulted() || !servos.i2cOk(0) || !servos.i2cOk(1)) {
      r->send(503, "text/plain", "PCA9685 is unavailable; calibration output is disabled");
      return;
    }
    int ch = -1, us = 0, low = 0, high = 0;
    if (!parseControlInteger(r->getParam("ch")->value().c_str(), 0, N_CH - 1, ch)) {
      r->send(400, "text/plain", "ch must be an integer in 0..31");
      return;
    }
    if (!servos.calibrationPulseRange(ch, low, high)) {
      r->send(409, "text/plain", "ch is unused or not a supported calibration axis");
      return;
    }
    if (!parseControlInteger(r->getParam("us")->value().c_str(), low, high, us)) {
      r->send(400, "text/plain", "us is outside the axis-safe pulse range");
      return;
    }
    if (!httpMutationAllowed(r)) return;
    cal_ch = ch;
    cal_us = us;
    r->send(200, "text/plain", "selected");
  });
#endif
  server.on("/trim", HTTP_GET, [](AsyncWebServerRequest* r) {
    if (r->hasParam("ch") && r->hasParam("us")) {
      int channel, trim;
      if (!parseControlInteger(r->getParam("ch")->value().c_str(), 0, N_CH - 1, channel) ||
          !parseControlInteger(r->getParam("us")->value().c_str(), -200, 200, trim)) {
        r->send(400, "text/plain", "invalid channel or trim");
        return;
      }
      if (!httpMutationAllowed(r)) return;
      servos.setTrim(channel, trim);
      r->send(200, "text/plain", "ok");
      return;
    }
    String out = "[";
    for (int i = 0; i < N_CH; i++) {
      out += servos.trim(i);
      if (i < N_CH - 1) out += ",";
    }
    out += "]";
    r->send(200, "application/json", out);
  });
  server.on("/wifi", HTTP_GET, [](AsyncWebServerRequest* r) {
    refreshWifiState();
    JsonDocument doc;
    doc["ssid"] = staSsid;
    doc["connected"] = WiFi.status() == WL_CONNECTED;
    doc["ip"] = WiFi.status() == WL_CONNECTED ? WiFi.localIP().toString() : "";
    doc["ap_ready"] = wifiApReady;
    doc["sta_configured"] = wifiStaConfigured;
    doc["state"] = wifiStaState;
    String out;
    serializeJson(doc, out);
    r->send(200, "application/json", out);
  });
  server.on("/wifi", HTTP_POST, [](AsyncWebServerRequest* r) {
    // STA (iPhone テザリング) 資格情報の保存。フォーム値は Web UI 設定
    // タブからのみ受け付ける (ハードコード禁止)
    if (r->hasParam("ssid", true)) {
      const String ssid = r->getParam("ssid", true)->value();
      const String pass = r->hasParam("pass", true)
                               ? r->getParam("pass", true)->value()
                               : String();
      if (!validWifiCredentials(ssid, pass)) {
        r->send(400, "text/plain", "ssid/password is invalid or a placeholder");
        return;
      }
      if (!httpMutationAllowed(r)) return;
      Preferences p;
      p.begin(STA_PREFS_NS, false);
      p.putString("ssid", ssid);
      p.putString("pass", pass);
      p.end();
      staSsid = ssid;
      wifiStaConfigured = true;
      wifiStaState = "CONNECTING";
      WiFi.begin(ssid.c_str(), pass.c_str());
    } else {
      r->send(400, "text/plain", "ssid and pass are required");
      return;
    }
    r->send(202, "text/plain", "connection attempt started");
  });
  server.begin();
}

void setup() {
  Serial.begin(115200);
  randomSeed(esp_random());  // 目のサッカード用
  Wire.begin(PIN_SDA, PIN_SCL);
  servos.begin();
  // ADC 分圧の成立を観測するまで通常PWMは許可しない。校正ビルドの単一軸
  // 診断だけが calibrateUs(..., diagnostic=true) として別経路を持つ。
  servos.setPowerReady(false);
  peri.begin();
  setupWiFi();
  setupWeb();
  audio.begin(&wsAudio);
  #ifdef CALIBRATION_MODE
  servos.enableAll();
#endif
  if (!servos.i2cOk(0) || !servos.i2cOk(1))
    Serial.printf("!! PCA9685 not responding: board0=%d board1=%d (check wiring / A0 jumper)\n",
                  servos.i2cOk(0), servos.i2cOk(1));
  // タスク WDT: loop が 3 秒止まったら再起動。再起動完了までは PCA に旧 PWM が残る。
  esp_task_wdt_init(3, true);
  esp_task_wdt_add(NULL);
  peri.queueTrack(1);  // 起動音 (SD にあれば, loop 側で再生)
  Serial.printf("Hardware profile: %s; status LEDs=%d; DFPlayer=%d; I2S=%s; AP=%d; STA=%s\n",
                HARDWARE_PROFILE, STATUS_LEDS_ENABLED, DFPLAYER_ENABLED,
                audio.stateName(), wifiApReady, wifiStaState.c_str());
  Serial.println("Tachikoma booted: PWM stays off until VBAT is verified and start is explicit");
}

void loop() {
  static uint32_t lastUs = micros();
  static uint32_t lastTelem = 0;
  esp_task_wdt_reset();
  const uint32_t nowUs = micros();
  float dt = (nowUs - lastUs) * 1e-6f;
  if (dt < 0.02f) return;  // 50Hz 制御
  lastUs = nowUs;
  // 1 周期が伸びても (NVS 書込・I2C 詰まり) 位相を一気に進めない (F-03)
  if (dt > 0.05f) dt = 0.05f;

  // 電源サンプルをPWM/制御より先に更新する。範囲外の瞬時値でも次の
  // サーボ書込みを許可しない。
  peri.samplePower();
  const bool vbatVerified = peri.vbatVerified();
  servos.setPowerReady(vbatVerified);
#ifndef CALIBRATION_MODE
  if (!vbatVerified) {
    // VBAT が未成立/範囲外になった時点で、stand と WS 所有権を捨てる。
    // 復電しても以前の stand を再利用せず、クライアントの明示 heartbeat
    // + stand=1 を再度受けるまで PWM を出さない。
    portENTER_CRITICAL(&controlMux);
    pendingControl.vx = pendingControl.vy = pendingControl.wz = 0;
    pendingControl.ptt = false;
    pendingControl.stand = false;
    pendingControl.armAction = 0;
    controlClientId = 0;
    portEXIT_CRITICAL(&controlMux);
  }
#endif

  portENTER_CRITICAL(&controlMux);
  // 期限切れ値をメールボックスからも消す。millis の周回で古い速度を復活させない。
  if (millis() - pendingControl.lastCmdMs > CONTROL_LEASE_MS) {
    pendingControl.vx = pendingControl.vy = pendingControl.wz = 0;
    pendingControl.ptt = false;
    pendingControl.stand = false;
    controlClientId = 0;
  }
  const ControlState control = pendingControl;
  pendingControl.armAction = 0;
  portEXIT_CRITICAL(&controlMux);
  arms.target[0] = control.arm;
  arms.mirror = control.mirror;
  if (control.armAction == 1) {
    const float pose[3] = {control.arm.yaw, control.arm.pitch, control.arm.elbow};
    arms.setPose(pose);
  } else if (control.armAction == 2) arms.startWave();
  eyes.mode = control.eyeMode;

  servos.serviceFault();
  servos.persistTrims();

  // 音声 PTT: 通信断 (UI 切断) で自動解除する (歩行指令と同じフェイルセーフ)。
  // 歩行制御 (CALIBRATION_MODE) と無関係に、通常運用外でも音声だけは動く
  {
    static bool pttPrev = false;
    const bool pttRequested = (millis() - control.lastCmdMs > CONTROL_LEASE_MS) ? false : control.ptt;
    if (pttRequested != pttPrev || (pttRequested && !audio.ready())) {
      const bool accepted = audio.setPtt(pttRequested);
      pttPrev = accepted ? pttRequested : false;
    }
  }

  bool telemetryStand = false;
  bool telemetryLease = true;
#ifdef CALIBRATION_MODE
  peri.setLedMode(LED_IDLE);
  peri.tick(false);
  const bool calibrationOutput =
      servos.calibrateUs(cal_ch, cal_us, peri.cutout(), control.stand,
                         true);  // 単一軸の安全な診断だけを許可
  telemetryStand = calibrationOutput && cal_ch >= 0 && !peri.cutout();
#else
  const bool timeout = millis() - control.lastCmdMs > CONTROL_LEASE_MS;
  const float vx = timeout ? 0 : control.vx;
  const float vy = timeout ? 0 : control.vy;
  const float wz = timeout ? 0 : control.wz;

  // 低電圧カット: VBAT_CUT 未満 3 秒で脱力ラッチ (peripherals.h)
  const bool standAllowed = control.stand && !timeout && vbatVerified && !peri.cutout();
  telemetryStand = standAllowed && servos.ready();
  telemetryLease = !timeout;

  // 起動/脱力の状態遷移
  static bool wasStanding = false;
  static LegOutput legOutput;
  static bool legCurInit = false;   // 脚スルー段の初期化フラグ (F-01)
  if (!standAllowed) gait.stop();
  if (standAllowed && !wasStanding) { servos.enableAll(); legCurInit = false; arms.resetOutput(); eyes.resetOutput(); }  // 再起動: ソフトスタート
  if (!standAllowed && wasStanding) servos.disableAll();  // 脱力: パルス停止
  wasStanding = standAllowed;
  if (standAllowed) servos.softStart();

  // legs[] は下の arms.update() (脚×腕連成クランプ) でも参照するため if
  // ブロックの外側で宣言する。2つの if は同一条件 (standAllowed &&
  // servos.ready()) なので、後段が実行される時点では必ず本ブロックで
  // 更新済み — 未初期化のまま読まれることはない
  LegCmd legs[4];
  if (standAllowed && servos.ready()) {
    gait.bodyH = control.h;
    gait.update(dt, vx, vy, wz, legs);
    // 出力スルー段 (arms.h の cur_ と同じ 2 段構え)。無信号→有信号の初回は
    // 「現在角は不明」なので中立 (0°) から LEG_SLEW_DPS で目標へ寄せる (F-01/F-03)
    if (!legCurInit) { legOutput.reset(); legCurInit = true; }
    legOutput.update(dt, legs);
    for (int leg = 0; leg < 4; leg++) {
      const JointAngles& angle = legOutput.angle(leg);
      servos.writeJoint(leg, 0, angle.yaw);
      servos.writeJoint(leg, 1, angle.pitch);
      servos.writeJoint(leg, 2, angle.knee);
    }
    // CH_HEAD の機構は未確定。割当が確定するまでは未使用・full-off を維持する。
  }

  const bool walking = standAllowed && servos.ready() && gait.moving();  // gait と同じ判定 (F-04)
  if (standAllowed && servos.ready()) {
    // 前脚(FR/FL)×腕 連成クランプ用 (arms.h ARM_LEG_YAW_GATE_DEG 参照)。
    // 目標とスルー後の出力を比べ、危険側の値で退出中の退避を維持する
    const JointAngles legAng[2] = {legOutput.armGuard(0, legs),
                                 legOutput.armGuard(1, legs)};
    arms.update(dt, servos, walking, gait.phase(), control.h, legAng);
    eyes.update(dt, servos, vy, wz);  // vy=前後 (進行方向バイアス)
  }
  peri.setLedMode(!control.led ? LED_OFF : (walking ? LED_ACTIVE : LED_IDLE));
  peri.tick(walking);
#endif

  if (millis() - lastTelem > 500) {
    lastTelem = millis();
    refreshWifiState();
    JsonDocument doc;
    addFeatureTelemetry(doc);
    doc["vbat"] = peri.vbat();
    doc["h"] = control.h;
    doc["low"] = peri.lowBattery();
    doc["cut"] = peri.cutout();
    doc["stand"] = telemetryStand;
    doc["lease_valid"] = telemetryLease;
    doc["vbat_verified"] = peri.vbatVerified();
    doc["vbat_state"] = peri.vbatState();
    // PCA V+ / servo rail に電圧センサを設けていないため、ここは常に
    // UNVERIFIED。VBAT の検知をサーボ V+ の通電確認として表示しない。
    doc["servo_rail_verified"] = false;
    doc["servo_rail_state"] = "UNVERIFIED_NO_SENSOR";
    doc["wifi_ap_ready"] = wifiApReady;
    doc["wifi_sta_state"] = wifiStaState;
    doc["i2c"] = servos.i2cOk(0) && servos.i2cOk(1);  // PCA9685 ×2 応答 (F-05)
    String out;
    serializeJson(doc, out);
    ws.textAll(out);
    ws.cleanupClients();
  }
}

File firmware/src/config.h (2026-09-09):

#pragma once
#include <stdint.h>
// タチコマ歩行ファームウェア 設定
// 幾何値は hardware/src/config.py と一致させること

// ---------------- 幾何 (mm)
constexpr float COXA_LEN  = 26.0f;   // ヨー軸→股ピッチ軸 (水平)
constexpr float FEMUR_LEN = 70.0f;   // 股ピッチ軸→膝軸 (STD サーボ構成)
// TIBIA_LEN: ik.h の IK/FK 計算だけが使う「実効 (ground-equivalent) tibia
// 長」。物理リンク長 (hardware/src/make_leg.py の tibia_link()/
// leg_foot_bored() が使う実寸) は 135.0mm で無変更 — 足の実体
// (leg_foot_bored+foot_pad) は膝軸から見た tibia の物理原点 (=旧
// TIBIA_LEN=135 の到達点) よりさらに foot_pad 底まで実体があり、しかも
// tibia 軸は SWAY 込みの実スタンス姿勢によって鉛直から最大 20° 以上傾く
// ため、旧・鉛直時の一次元近似 (foot_pad 底の深さ 11.358mm をそのまま加算)
// では体高105mm・SWAY 込みの最悪位相で world z 残差が最大 3.5mm 残ることが
// 判明した。tools/sim_gait.py の実際の foot_target()/leg_ik() (SWAY 込み)
// を使い、実運用スタンス全域 (体高105-130mm, 全位相) を物理配置チェーンで
// 数値評価し、最悪ケースがちょうど world z=0 に接する (めり込まない)
// FOOT_GROUND_OFFSET=20.98mm で数値校正した (2026-09-04 ホスト計算、実機未確認, hardware/
// src/config.py FOOT_GROUND_OFFSET 参照)。135+20.98=155.98 (config.py
// TIBIA_LEN_GAIT と一致させること。tools/sim_gait.py が regex 突合で
// 検査する)。ik.h はこの定数を物理形状目的では使っていないため、値を
// 実効値にしても他の意味は壊れない。
constexpr float TIBIA_LEN = 155.98f;  // 膝軸→足先接地点 (実効値, IK専用)。2026-09-04 校正値
                                      // (重心対応スタンスで最悪位相の脛傾きが増えた分の再校正,
                                      // config.py FOOT_GROUND_OFFSET 20.98)
constexpr float HIP_R = 50.9f;       // ヨー軸の配置半径 (円形ハブ v3, 放射配置)

// 脚インデックスと取付方位 (脚が伸びる向き, ボディ座標 +X右 +Y前)
// v3 (2026-07-28): 公式フィギュア下面実測 — 前脚±75°/後脚±120° (正面基準)。
// 真後ろ 270° はポッド接続ネックのステーション (config.py と一致必須)
enum LegId { FR = 0, FL = 1, RL = 2, RR = 3 };
constexpr float LEG_MOUNT_DEG[4] = {15.0f, 165.0f, 210.0f, 330.0f};
// 中立スタンスの足先方位 (取付方位と別)。公式フィギュアのポーズ準拠で
// 前脚は前寄り (中立ヨー+18°)・後脚はやや外拡げ (-2°)。後脚を内へ寄せる
// と FR-RL 対角線が重心に接近し前脚遊脚の安定が崩壊する (sim_gait [4])
constexpr float STANCE_DEG[4] = {33.0f, 147.0f, 208.0f, 332.0f};
constexpr float LEG_ORIGIN[4][2] = {  // ヨー軸のボディ座標 {x, y} = HIP_R∠mount
    {+49.166f, +13.173f}, {-49.166f, +13.173f},
    {-44.081f, -25.450f}, {+44.081f, -25.450f}};

// ---------------- サーボ
// PCA9685 ×2: board0=0x40 (脚+頭 ch0-12), board1=0x41 (腕 ch16-23 + 目 ch24-26)
// グローバル ch = board*16 + ローカル ch
constexpr int SERVO_FREQ = 50;            // Hz
constexpr uint8_t PCA_ADDR[2] = {0x40, 0x41};
constexpr int N_CH = 32;
constexpr int PCA_CH[4][3] = {            // [leg][yaw, pitch, knee]
    {0, 1, 2}, {3, 4, 5}, {6, 7, 8}, {9, 10, 11}};
constexpr int CH_HEAD = 12;
// 腕: [arm][yaw, pitch, elbow]  arm0=右, arm1=左。ch 19/23 (旧グリップ)
// は未使用 (2026-07-29 固定爪化でグリッパ機構ごと廃止。配線/PCA9685
// 割当は変えず ch 番号のみ予約のまま残す)
constexpr int ARM_CH[2][3] = {{16, 17, 18}, {20, 21, 22}};
// 目 (頭部, SUBMICRO)。元キットの目パーツ (白ドーム) を自軸回転させる。
// 黒ドット群 (視線マーク) が軸から ~45° 偏心しており、回転で視線が泳ぐ。
// 2026-07-28 設計変更: 中央目 (ch25) は固定カメラ目 (hardware/src/
// make_camera.py) に置換済みでサーボを持たない — ch 番号はそのまま予約し
// (配線/PCA9685 割当を変えない)、eyes.h の Eyes::update() が未使用として
// スキップする。可動 (キョロキョロ) するのは右目 (ch24)・左目 (ch26) のみ
constexpr int EYE_CH[3] = {24, 25, 26};   // 右目, 中央(未使用/固定カメラ), 左目
constexpr float EYE_LIM = 80.0f;          // サーボ回転の使用範囲 ±
constexpr float EYE_SLEW_DPS = 500.0f;    // サッカードの速さ
// 左腕はヨーのみソフトでミラー (ピッチ/肘はパーツが左右ミラー印刷なので
// 符号そのまま。arms.h の出力部を参照。2026-07-29 固定爪化でグリップ軸は
// 廃止済み)
constexpr int ARM_SIGN[2] = {+1, -1};
constexpr int US_MIN = 500, US_MAX = 2500; // サーボパルス範囲
constexpr float DEG_RANGE = 180.0f;        // US_MIN..US_MAX に対応する角度
constexpr int DFPLAYER_TRACK_MAX = 9999;   // mp3/0001.mp3〜9999.mp3 の4桁範囲
// 通常動作の指令リース。期限切れでは速度だけをゼロにせず、stand と PWM を
// 停止し、再開には明示的な stand=1 を要求する (main.cpp)。
constexpr uint32_t CONTROL_LEASE_MS = 1500;
// 校正 API はサーボの電気的端点 (500/2500us) を直接叩かせない。実際の
// 機構リミットから算出した範囲に加え、上下端に 100us の保護余裕を取る。
// これは単体・無負荷・ホーンを外した診断モード専用であり、実機の角度校正を
// 合格にする値ではない。
constexpr int CAL_ENDPOINT_MARGIN_US = 100;
// 関節ソフトリミット (deg, 機構設計値。assembly.md 参照)
constexpr float LIM_YAW = 40.0f;   // v3: 前脚が腕マウントから 35° 離れたため
                                   // ±35→±40 に緩和 (中立ヨー +18° + 歩容 ~22°。
                                   // 2026-07-28 腕マウント移設後の角度差は 35°
                                   // (本ファイル下部 ARM_YAW_LIM 注記と同一根拠)。
                                   // check_leg_assembly / check_arm[1b] で実メッシュ検証)
// v3: 45° ペア (FR↔RR, FL↔RL) が互いへヨーすると脚が交差し得るため、
// 「ペア相手方向 (内側)」のヨーを 2 段で制限する (check_leg_assembly で
// 実メッシュ検証。FR/RL はミラー脚 _m 前提):
//  1) 単側 ≤ LIM_YAW_IN (単側 18° の深タック姿勢から交差が始まる実測)
//  2) ペア同時内側の和 ≤ LIM_YAW_IN_SUM (対称 (17.5,17.5)=和35 は交差)
// 歩容の使用量は単側 ~16.6° / 和 ~8.6° (sim_gait [2b])
constexpr float LIM_YAW_IN = 17.5f;
constexpr float LIM_YAW_IN_SUM = 26.0f;
// 内側ヨーの符号: FR は RR へ CW(-), FL は RL へ CCW(+), RL は FL へ CW(-),
// RR は FR へ CCW(+)
constexpr int YAW_IN_SIGN[4] = {-1, +1, -1, +1};
// v3: ポッド (Cabin) が後方の脚と同じ高さに接続されるため、後脚の
// ポッド側 (後方中央向き) ヨーを別途制限する。歩容の使用量は ~15.4°、
// check_leg_assembly でこの限界値 × IK 到達姿勢の実メッシュ干渉 0 を検証
constexpr float LIM_YAW_POD = 30.0f;  // 2026-09-04: 22→30。実メッシュ掃引 (IK 到達極値姿勢) で
                                       // ポッド/バッテリー実体との接触は 34° から (32° まで 0.000cm³)。
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

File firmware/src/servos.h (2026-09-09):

#pragma once
#include <Adafruit_PWMServoDriver.h>
#include <Preferences.h>
#include <Wire.h>
#include "config.h"

// PCA9685 ×2 ラッパ: 角度(deg)→パルス、トリム管理、ソフトスタート。
// グローバル ch 0-31 (board = ch/16, ローカル = ch%16)。
// トリムの NVS 保存はライトビハインド (setTrim は RAM のみ、persistTrims が
// 静穏 2 秒後にまとめて書く)。
class Servos {
 public:
  void begin() {
    Wire.setTimeOut(5);  // バス喪失で停止処理自体が長時間詰まることを避ける
    for (int b = 0; b < 2; b++) {
      pwm_[b] = Adafruit_PWMServoDriver(PCA_ADDR[b]);
      i2cOk_[b] = pwm_[b].begin();   // PCA9685 が I2C に応答したか (F-05)
      if (i2cOk_[b]) {
        i2cOk_[b] = fullOffBoard(b);  // 周波数再設定前に残留パルスを消す
        pwm_[b].setOscillatorFrequency(25000000);
        pwm_[b].setPWMFreq(SERVO_FREQ);
        prescale_[b] = (uint8_t)(pwm_[b].getOscillatorFrequency() /
                                 (SERVO_FREQ * 4096.0f) + 0.5f - 1.0f);
        i2cOk_[b] = i2cOk_[b] && configurationOk(b);
      }
      if (!i2cOk_[b]) fault_ = true;
    }
    prefs_.begin("trim", false);
    for (int i = 0; i < N_CH; i++) {
      trim_us_[i] = constrain(prefs_.getShort(key(i).c_str(), 0), -200, 200);
      enabled_[i] = false;
      used_[i] = false;
    }
    // 使用チャンネルの登録 (softStart の対象)
    for (int leg = 0; leg < 4; leg++)
      for (int j = 0; j < 3; j++) used_[PCA_CH[leg][j]] = true;
    // CH_HEAD は機構未確定。未使用のまま full-off を維持する。
    for (int a = 0; a < 2; a++)
      for (int j = 0; j < 3; j++) used_[ARM_CH[a][j]] = true;
    used_[EYE_CH[0]] = used_[EYE_CH[2]] = true;  // 中央は固定カメラ
    disableAll();  // ESP32 だけの再起動でも PCA に残った旧パルスを消す
  }

  // VBAT の成立確認。通常動作では false の間、ready と通常 PWM を禁止する。
  // CALIBRATION_MODE の単一軸診断は calibrateUs(..., diagnostic=true) だけが
  // このゲートを迂回できる。
  void setPowerReady(bool ready) {
    if (powerReady_ == ready) return;
    powerReady_ = ready;
    if (!ready) {
      disableAll();
      calibrationAllowed_ = false;
      calibrationChannel_ = -1;
    }
  }

  bool powerReady() const { return powerReady_; }

  // 順次イネーブル (突入電流対策)。loop から繰り返し呼ぶ
  void softStart() {
    if (fault_ || !powerReady_ || started_ >= N_CH) return;
    if (millis() - lastStart_ < 100) return;
    while (started_ < N_CH && !used_[started_]) started_++;
    if (started_ < N_CH) {
      const int ch = started_++;
      enabled_[ch] = true;
      // enabled の印だけでは ready 後に全軸が同時始動してしまう。
      // 組立時に合わせる中立パルスをここで 1 軸だけ出して順次通電する。
      writeDeg(ch, 0.0f);
    }
    lastStart_ = millis();
  }
  bool ready() const {
    if (fault_ || !powerReady_) return false;
    for (int i = 0; i < N_CH; i++)
      if (used_[i] && !enabled_[i]) return false;
    return true;
  }

  void writeDeg(int ch, float deg) {
    if (ch < 0 || ch >= N_CH || !enabled_[ch] || !powerReady_ || !isfinite(deg)) return;
    float us = 1500.0f + deg * (US_MAX - US_MIN) / DEG_RANGE + trim(ch);
    us = fminf((float)US_MAX, fmaxf((float)US_MIN, us));
    writeUs(ch, (int)us);
  }

  void writeJoint(int leg, int joint, float deg) {
    writeDeg(PCA_CH[leg][joint], deg * JOINT_SIGN[leg][joint]);
  }

  // CALIBRATION_MODE 用の安全な単一軸診断。ch と us の両方を明示し、機構軸
  // ごとの保護範囲を満たすときだけ、その軸へ絶対パルスを出す。他の軸は先に
  // PCA の ALL_LED_OFF で停止する。電源未検証の USB ベンチを許すのは、呼出側
  // が専用の diagnostic=true を明示した場合だけで、通常制御からは到達できない。
  bool calibrateUs(int ch, int us, bool cutout, bool stand,
                   bool diagnostic = false) {
    int low = 0, high = 0;
    const bool allowed = diagnostic && stand && !cutout &&
                         calibrationPulseRange(ch, low, high) &&
                         us >= low && us <= high;
    if (!allowed) {
      if (calibrationAllowed_ || calibrationChannel_ >= 0) disableAll();
      calibrationAllowed_ = false;
      calibrationChannel_ = -1;
      return false;
    }
    if (!calibrationAllowed_ || calibrationChannel_ != ch) {
      disableAll();
      if (fault_) return false;
      enabled_[ch] = true;
      started_ = N_CH;
      calibrationChannel_ = ch;
      calibrationAllowed_ = true;
    }
    writeUs(ch, us);
    return !fault_;
  }

  // 単軸選択を解除する明示的な停止。次周期以降に出力は残さない。
  void stopCalibration() {
    if (calibrationAllowed_ || calibrationChannel_ >= 0) disableAll();
    calibrationAllowed_ = false;
    calibrationChannel_ = -1;
  }
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

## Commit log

2026-08-22 Initial public release: Tachikoma walking robot conversion project
    12-servo quadruped conversion of the TACHIKOMA 3D-print kit: parametric
    skeleton (manifold3d), ESP32+PCA9685 firmware with crawl gait, print
    plates for Bambu Lab X2D, URDF export, and full build documentation.
    Code is MIT licensed; 3D model data, docs and media are CC BY-NC-SA 4.0
    (unofficial, non-commercial fan project — see LICENSE-MODELS.md).
    [Arm_Left.stl, Arm_Left_Claw_Grey.stl, Arm_Left_Elbow_Grey.stl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]
2026-09-03 Add issue-driven build plan: 72 GitHub issues as code, templates, CONTRIBUTING
    - tools/issues/plan.py: milestones (M0-M5 Go/No-Go gates), scoped labels,
    8 epics + 64 tasks with parent/blocked-by relations (validated, acyclic)
    - tools/issues/sync_github_issues.py: idempotent sync to GitHub Issues
    (labels, milestones, issues, sub-issues, dependencies) + build_plan.md generator
    - tools/issues/setup_project.sh: Projects v2 board bootstrap (needs project scope)
    - .github/ISSUE_TEMPLATE: print job / assembly step / problem / decision forms
    - CONTRIBUTING.md: how to pick up work, evidence rules, anti-patterns
    - docs/build_plan.md: critical path, parallel lanes, generated dependency graph
    Co-Au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
2026-09-03 Link GitHub Project board (Tachikoma 物理製作) from CONTRIBUTING, build_plan, P-08
2026-09-03 P-08: board swimlane set to レーン
2026-09-04 Pin espressif32@6.12.0 (build broke under stray pioarduino 55.x); seed make_head_eyecut sampling
    - firmware/platformio.ini: platform = espressif32@6.12.0 (Arduino core 2.0.17,
    legacy driver/i2s.h). Unpinned resolution picked pioarduino 55.3.311 and
    SCons died with TypeError; build is SUCCESS again (RAM 19.4% / Flash 71.7%).
    - tools/make_head_eyecut.py: checks [4b]/[5] used unseeded surface sampling
    and flipped OK/NG between runs (98.3/98.6/98.5%). Seeded + 24000 samples;
    now repeatable at 98.9%.
    - AGENTS.md: document the pin and the intelhex venv requirement.
2026-09-04 Add PETG_Walk_4_Rest plate (remaining PETG parts, generated 2026-08-31; verify OK)
    [PETG_Walk_4_Rest.3mf]
2026-09-04 Electrical review fixes: UBEC 6V check, 74AHCT125 OE pins, WS2812 chain, /cal sweep endpoint
    - wiring.md: 74AHCT125 1OE->GND (LEDs dead otherwise), unused OE->VCC; WS2812
    index 2 must not be physically skipped (single-wire chain); UBEC output
    selector must be set to 6.0V and measured before any servo is connected;
    main switch carries both branches (8-14A class) -> measure at L-10.
    - BOM.md: #6/#12 notes, #29 quantity basis 2 eyes (center eye is camera).
    - assembly.md: §1-1 end-of-travel check (180 vs 270 deg servos) via
    CALIBRATION_MODE /cal?us=500|2500; §2-6 measure 6V/5V rails before servos.
    - firmware: Servos::allUs(), /cal?us= endpoint under CALIBRATION_MODE.
    Both builds SUCC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
    [main.cpp, servos.h]
2026-09-04 Firmware review fixes: leg output slew + dt clamp, monitoring in CALIBRATION_MODE, task WDT, I2C check
    - F-01/F-03: legs now pass through a slew stage (LEG_SLEW_DPS=240) like arms;
    on (re)enable the stage starts from neutral so the first pulses ramp instead
    of jumping from an unknown floating pose. Loop dt clamped to 50 ms so a long
    cycle (NVS/I2C stall) cannot advance the gait phase in one step.
    - F-02: peri.tick() (VBAT average, low-voltage cutout, telemetry) now also
    runs in CALIBRATION_MODE builds.
    - F-04: 'walking' uses Gait::moving() (same hysteresis as the gait itself).
    - F-05: PCA9685 begin() result kept; boot log + telemetry 'i2c' flag.
    - F-06: esp_task_wdt 3 s on loop. F-08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
    [config.h, gait.h, main.cpp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]
2026-09-04 Full design review: CG-aware gait, tibia knee-neck strength fix, checkers, docs, issues
    Findings from the 2026-09-04 whole-repo review (systems / mechanical / docs):
    Gait (S-01/S-02): the stability margin assumed the CG at the body origin, but the
    URDF mass model puts it at y=-39mm (Cabin). polygon_margin now uses config.CG_XY;
    the neutral foot pattern is shifted rearward (STANCE_OFF_XY -30), rear-leg SWAY
    raised to 40mm, BODY_H_MIN 105->110, LIM_YAW_POD 22->30 (mesh contact starts at
    34deg). Worst-case margin -23.7 -> +10.9mm, IK failures 0. sim_gait [3] now sweeps
    all commands/phases with 3/4-point static leg loads: worst hip torque 18.5 kgf.cm
    (was a single-point 8.9). FOOT_GROUND_OFFSET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
    [PETG_2_Tibia.3mf, PETG_Walk_3_Tibia.3mf, PLA_Matte_Blue_5_HeadTop.3mf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]
2026-09-04 Servo-spec check for L-11, buildability audit: PR-10 camera-base reprint, purchase gaps
    - L-11: verified voltage ranges (DS3218MG 4.8-6.8V, LD-20MG 6-7.4V, LD-220MG
    6-8.4V dual-shaft H51.4; MG90S/ES9251II 6.0V max) -> 7.4V bus needs a separate
    6V rail and, on 2S, cannot be held by the buck UBEC -> not recommended; options
    reordered (low-torque gait / higher-torque same-case servo first).
    - P-03: which servo actually arrived must be identified (3 models in the docs).
    - PR-10 + PLA_Matte_White_3_CamBase plate: printed eye_pod_camera_base is an old
    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
    [PETG_3_Femur.3mf, PETG_4_CoxaArm.3mf, PETG_Walk_2_CoxaFemur.3mf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]
2026-09-05 実機設計を再監査し、制御・内部形状・検証基盤の不具合を修正する
    開始時515ファイルを用途別に点検し、全STL/URDFを再生成。
    実制御を含む89条件の物理計算と18姿勢の干渉検査を保存した。
    最終23検査は14合格・8不合格・1未検証。頭部収納、支持、脚装飾、
    TPU足裏などの未解決事項を残し、実機の組立・歩行合格とは扱わない。
    元モデル・既存3MF・旧画像動画を保持。内部形状10 STLと配置2 STLを
    更新し、製作への影響・不採用候補・再現条件を監査報告に記録した。
    メーカー原本コピーと再生成できる衝突キャッシ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
    [FR_0_shoe_fitted_candidate.stl, FR_0_toe_hidden_seat_candidate.stl, FR_1_shoe_fitted_candidate.stl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]
2026-09-05 監査コミットをIssueへ紐付け、完了した検査5件と残課題を記録する
    11件の本文を生成元へ反映。全96本文と173依存を照合し、完了5件だけをClose/Doneに更新。他の進捗を保持。Issue同期の9回帰に合格。Refs #80, #85, #81, #82, #83, #84, #93
2026-09-05 購入履歴と全印刷部品を照合し96課題の依存と製作条件を更新
    [purchase-issue-map.tsv]
2026-09-05 全96課題とProjectの反映結果を記録
2026-09-08 公開候補を更新し印刷優先根拠を整理（WIP）
    [arm_l_forearm__col_0.stl, arm_l_forearm__vis_555555.stl, arm_l_forearm__vis_grey.stl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]
2026-09-08 AP設定説明を公開候補へ追加（WIP）
2026-09-08 公開反映結果と回帰試験を記録（WIP）
2026-09-09 最新監査リンクと公開候補容量を更新（WIP）
2026-11-13 docs: add RR leg trial print package
